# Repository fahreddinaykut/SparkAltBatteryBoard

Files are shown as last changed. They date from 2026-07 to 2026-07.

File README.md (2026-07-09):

# SparkAltBatteryBoard

A custom research-oriented battery interface and telemetry board for the DJI Spark platform, built around a standard 3S LiPo battery pack instead of the discontinued, hard-to-find OEM Smart Battery.

This project documents a reverse-engineered I2C/SMBus smart-battery communication interface, originally developed to study how the DJI Spark flight controller communicates with its battery pack. The board sits between a standard 3S pack and the drone, reads the real cell voltages and current, and reproduces that communication interface.

<p align="center">
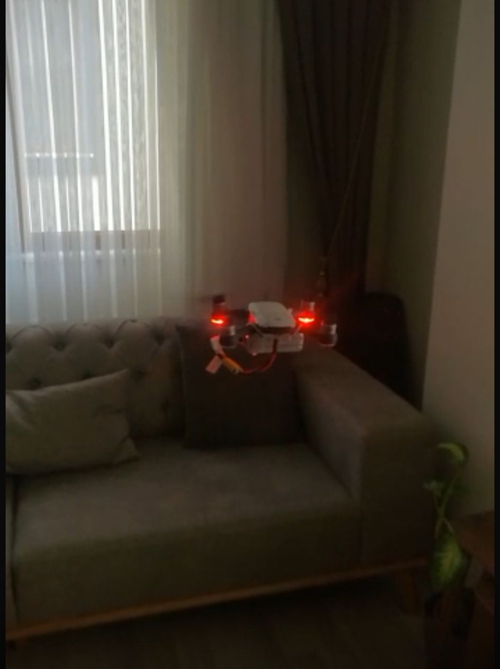
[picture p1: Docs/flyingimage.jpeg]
DJI Spark flying on SparkAltBatteryBoard
  
</p>

## How it works

1. The original DJI Spark Smart Battery was disassembled and its I2C/SMBus traffic with the flight controller was captured with a Saleae Logic Analyzer.
2. That traffic was decoded to recover the SBS + DJI-proprietary command set (auth handshake, cell voltages, PEC/CRC-8, etc.) — see [`Docs/I2C_BMS_PROTOCOL.md`](Docs/I2C_BMS_PROTOCOL.md).
3. A custom PCB replicates the OEM battery's form factor and connector, with resistor dividers for per-cell voltage sensing and an INA199 current shunt amplifier.
4. An ATmega328P on the board reproduces the Smart Battery communication interface over I2C in real time — computing PEC on the fly and clock-stretching where needed. See [`Firmware/README.md`](Firmware/README.md) for the full protocol implementation.

<p align="center">
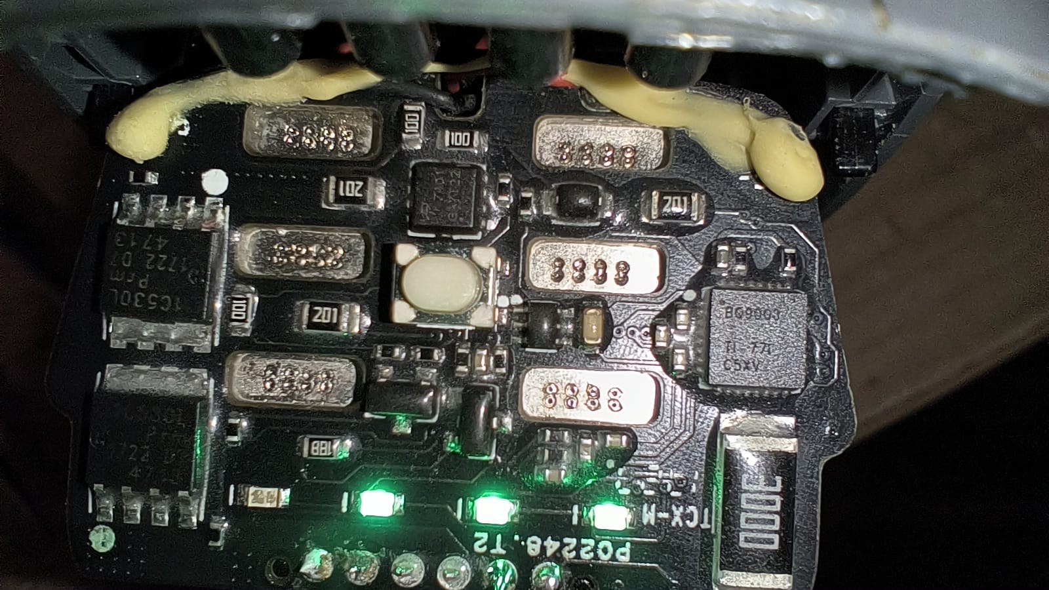
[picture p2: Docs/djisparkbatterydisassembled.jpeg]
Original DJI Spark battery, disassembled for reverse engineering
  
</p>

## Repository structure

| Folder | Contents |
|---|---|
| [`Hardware/`](Hardware) | KiCad project: schematics, PCB layout, 3D connector models, Gerbers, BOM |
| [`Firmware/`](Firmware) | PlatformIO project for the ATmega328P I2C/SMBus battery emulator |
| [`Mechanical/`](Mechanical) | Battery mount 3D model (STEP) |
| [`Docs/`](Docs) | Schematic PDF, protocol reverse-engineering notes, raw sniffed I2C sessions, reference photos/video |

## Hardware

| Top | Bottom | Layout |
|---|---|---|
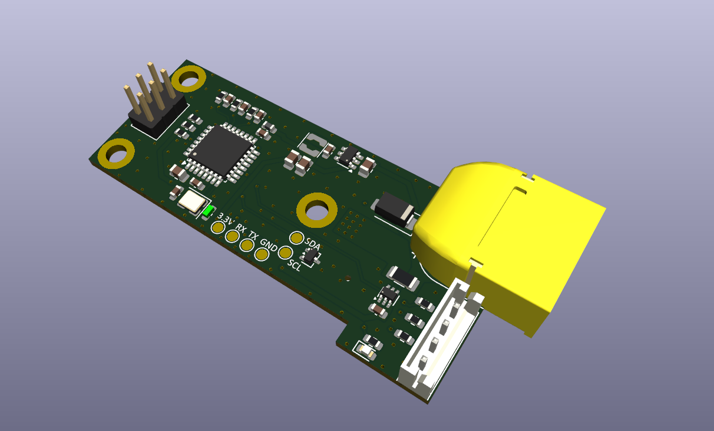
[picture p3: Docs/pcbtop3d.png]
PCB top 3D
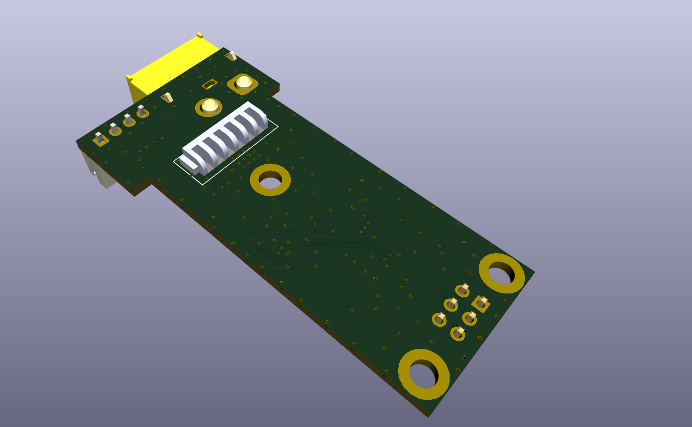
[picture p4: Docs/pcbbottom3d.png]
PCB bottom 3D
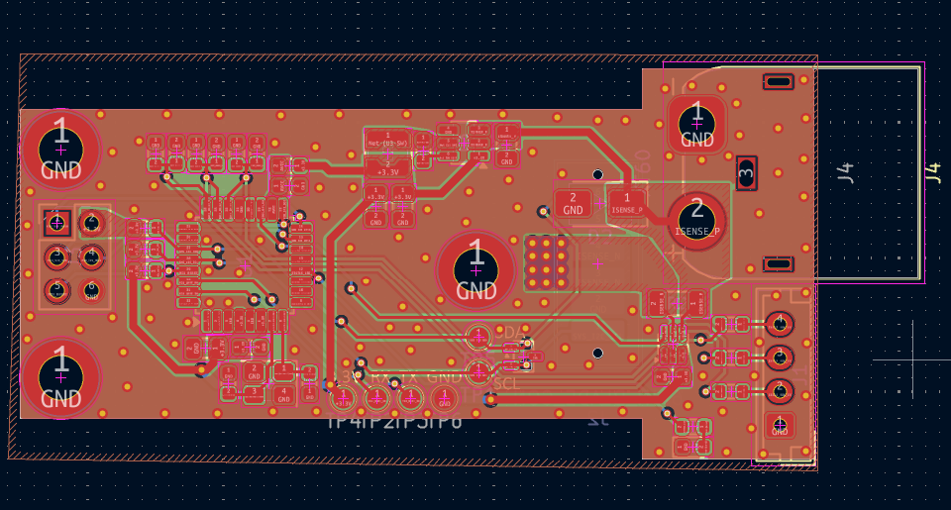
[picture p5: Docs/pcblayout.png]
PCB layout
|  |  |  |

- **MCU:** ATmega328P — chosen specifically because its hardware TWI peripheral supports I2C clock stretching reliably, which the DJI FC's polling requires (see [`Firmware/README.md`](Firmware/README.md#hardware) for why an ESP32 doesn't work here).
- **Sensing:** 3-way resistor divider network for per-cell voltage taps, INA199 shunt amplifier for pack current.
- **Full schematic:** [`Docs/SparkAltBatteryBoardV1.pdf`](Docs/SparkAltBatteryBoardV1.pdf)
- **Fabrication outputs:** [BOM](Hardware/Fabrication/SparkAltBatteryBoard_BOM.csv) · [Gerbers](Hardware/Fabrication/SparkAltBatteryBoard_Gerbers.zip)
- **Battery mount:** [`Mechanical/batterymount.stp`](Mechanical/batterymount.stp)

### PCB Design / Manufacturing Notes

The PCB revision was prepared as a manufacturing-oriented KiCad project, not only as a proof-of-concept schematic.

Design considerations include:

- Hierarchical schematic structure
- Separated MCU, power, sensing, and connector blocks
- 3.3 V I2C/SMBus logic interface
- ADC-scaled cell-voltage sensing inputs
- RC filtering on analog measurement lines
- INA199 high-side current-sense frontend
- Kelvin-style shunt measurement routing approach
- Buck-regulated 3.3 V system rail
- I2C pull-up resistors
- ESD/TVS protection on external communication lines
- AVR ICSP programming/debug header
- Wide copper routing/polygon strategy for battery current path
- Manufacturing outputs prepared: BOM and Gerber package

## Firmware

PlatformIO project targeting the ATmega328P (Arduino Uno/Nano pinout). Handles the I2C slave logic, ADC reads, CRC-8 PEC calculation, and all SBS/DJI command responses.

```
pio run -e uno
pio run -e uno -t upload
```

Full pin map, supported command table, and known limitations: [`Firmware/README.md`](Firmware/README.md).

## Protocol reverse engineering

The raw logic analyzer captures used to decode the protocol are included for reference:

- [`Docs/sniffedsession2.csv`](Docs/sniffedsession2.csv)
- [`Docs/sniffedsession3.csv`](Docs/sniffedsession3.csv)
- Full write-up: [`Docs/I2C_BMS_PROTOCOL.md`](Docs/I2C_BMS_PROTOCOL.md)

## Legacy Prototype Flight Test

The video below shows an earlier prototype tested around 4 years ago. It does not represent a flight test of the redesigned PCB revision in this repository.

<video src="Docs/flyingvideo.mp4" controls width="100%" poster="Docs/flyingimage.jpeg">
  Your browser can't play the embedded video — <a href="Docs/flyingvideo.mp4">watch/download it here</a>.
</video>

## Disclaimer

This is a hobbyist reverse-engineering project, shared for educational purposes. Flying with a modified battery/BMS is at your own risk — verify cell voltages, current limits, and wiring yourself before flight. Not affiliated with or endorsed by DJI.

The original prototype was flight-tested in the past. The redesigned PCB revision in this repository has not yet been flight-tested because the original test drone was later damaged in a crash.

## License

Source-available for personal, educational, and research use. Commercial use is not permitted without written permission. See [`LICENSE`](LICENSE) (MIT with Commons Clause).

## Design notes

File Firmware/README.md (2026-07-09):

# SparkAltBatteryBoard Firmware

Firmware that reproduces the I2C/SMBus communication interface of the DJI Spark's original Smart Battery. The goal is to respond correctly to the SBS + DJI proprietary commands expected by the flight controller (FC), so that a third-party/aftermarket 3S LiPo battery pack can be used without triggering an "Invalid Battery" error or an emergency landing.

## Hardware

- **Target MCU:** ATmega328P (`nanoatmega328` in PlatformIO, Arduino Uno/Nano pinout).
- **Why ATmega328P:** The DJI FC polls the battery at high speed, and the slave needs a few microseconds to compute the PEC (CRC-8) before responding. This requires hardware **clock stretching** on the I2C slave side (physically holding SCL low). Most modern 32-bit MCUs (e.g. ESP32) don't reliably support clock stretching in their I2C slave peripheral; the ATmega328P's native TWI module handles it correctly.
- **I2C slave address:** `0x0B` (standard SBS battery address).

### Pin map (`src/main.cpp`)

| Pin | Define | Purpose |
|---|---|---|
| A7 | `BATTERY_PIN_1` | BATCELL1 net — cell1 divider tap (4.7k/10k) |
| A0 (PC0) | `BATTERY_PIN_2` | BATCELL2 net — cell1+cell2 divider tap (20k/10k) |
| A1 (PC1) | `BATTERY_PIN_3` | BATCELL3 net — full pack divider tap (33k/10k) |
| A6 | `CURRENT_PIN` | INA199 shunt amplifier output (current sense) |
| A3 | `THERMISTOR_PIN` | NTC input — unused on the current hardware revision (see Known Limitations) |
| 8 | `LED_PIN` | I2C activity LED |
| A4 / A5 | SDA / SCL | I2C bus (Arduino `Wire` library defaults) |

Each divider tap shares a common 10kΩ bottom resistor against a different top resistor (4.7k / 20k / 33k), stepping down each cumulative cell voltage into the ADC's 0–3.3V range. `readVoltage()` takes the matching ratio (`CELL1_DIVIDER_RATIO`, `CELL2_DIVIDER_RATIO`, `PACK_DIVIDER_RATIO`) as a parameter for each pin.

## Protocol

- **Bus:** SMBus, little-endian byte order.
- **PEC (Packet Error Checking):** Every response ends with a CRC-8 byte (poly `0x07`, computed in `pec()`). If the FC can't validate this byte it rejects the data and can trigger an emergency landing, so every dynamic response function computes the PEC on the fly over `[address+W, command, address+R, data_lo, data_hi]`.
- Commands fall into two groups:
  - **Dynamic commands:** computed from live ADC measurements and sent.
  - **Static commands:** fixed bytes sniffed from the original DJI battery, sent back verbatim (auth/handshake, serial number, manufacturer name, etc.) — the FC only cares that these are always present and consistent, not that they're live.

### Supported commands

| Command | Meaning | Type |
|---|---|---|
| `0x08` | Temperature | Dynamic (currently fixed at 25°C — no NTC) |
| `0x09` | Pack Voltage | Dynamic |
| `0x0A` | Current | Dynamic (INA199) |
| `0x0D` | Relative State of Charge | Emulated / placeholder |
| `0x0F` | Remaining Capacity | Emulated / derived/static placeholder |
| `0x10` | Full Charge Capacity | Static |
| `0x17` | Cycle Count | Fixed (1) |
| `0x18` | Design Capacity | Static |
| `0x19` | Design Voltage | Static |
| `0x1B` | Manufacture Date | Static |
| `0x1C` | Serial Number | Static |
| `0x20` | Manufacturer Name | Static |
| `0x21` | Device Name | Static |
| `0x3D` / `0x3E` / `0x3F` | Cell3 / Cell2 / Cell1 Voltage | Dynamic |
| `0x00` | Manufacturer Data (mux, sub-page `0x51`/`0x53`/`0x54`/`0x55`) | Static |
| `0xD6` | Auth handshake (`55 AA 66`) | Static |
| `0xD8` | Barcode / serial | Static |
| `0xD9` | Encrypted firmware version | Static |
| `0xD2`, `0xD5`, `0xC2`, `0x23`, `0x66`, `0x2F` | Other DJI proprietary commands | Static |

Note: This firmware is not a calibrated fuel-gauge implementation. SOC and remaining-capacity related values are emulated for protocol compatibility and should not be used as accurate battery state estimation.

## Build & flash

With PlatformIO:

```
pio run -e uno
pio run -e uno -t upload
```

## File layout

- `src/main.cpp` — I2C slave logic, ADC reads, PEC calculation, all command responses.
- `platformio.ini` — build target: ATmega328P, 16MHz, Arduino framework.
- `DJISPoofer.xlsx` — raw I2C command/response data collected during reverse engineering (reference).

## Known limitations

- Temperature: the physical NTC was removed on the current hardware revision, so `getThermistorReading()` returns a fixed 25°C (`2982`, in 0.1K units).
- Values like Design Voltage, Design Capacity, and Cycle Count are static/fixed and independent of the actual hardware (should be set by hand to match the real battery spec).

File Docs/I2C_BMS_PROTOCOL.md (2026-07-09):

# DJI Spark BMS I2C/SMBus Protocol Reverse Engineering

This document outlines the decoded I2C/SMBus communication protocol between the DJI Spark Flight Controller (FC) and its proprietary Smart Battery. The data was sniffed and decoded using a Saleae Logic Analyzer.

By understanding this protocol, we can emulate the original DJI battery using a custom microcontroller, allowing the use of a standard 3S LiPo battery pack without triggering FC lockouts or emergency landings.

## 1. Physical Layer & Bus Fundamentals

DJI utilizes the industry-standard **Smart Battery Data Specification (SBS)** over SMBus, layered with their own proprietary authentication commands to lock down the ecosystem.

* **Bus Protocol:** SMBus @ 100kHz
* **Battery I2C Address:** `0x0B` (Standard SBS Address)
* **Logic Level:** 3.3V
* **Byte Order:** Little-Endian (Least Significant Byte first)
* **Integrity Check:** PEC (Packet Error Checking) using **CRC-8** (Polynomial `0x07`). 
  * *Critical:* Every read transaction must conclude with a valid PEC byte. If the PEC is missing or incorrectly calculated, the FC will immediately reject the data and trigger an emergency drop.

---

## 2. Standard SMBus Commands (Dynamic Telemetry)

The FC continuously polls the battery for real-time telemetry. The responses are typically 2 bytes of payload data followed by 1 byte of PEC.

* **`0x08` - Temperature:** * Example Payload: `0xB6 0x0B` -> `0x0BB6` = `2998`
  * Math: Value is in 0.1 Kelvin. (299.8 K = **26.65 °C**)
* **`0x09` - Pack Voltage:** * Example Payload: `0x8B 0x31` -> `0x318B` = `12683`
  * Math: Value is in mV. Result = **12.68 V**
* **`0x0A` - Current:** * Example Payload: `0xD3 0xFD` -> `0xFDD3` = `64979`
  * Math: Represented in Two's Complement for discharge. Result = **-557 mA**
* **`0x0D` - Relative State of Charge (SOC):** * Example Payload: `0x60 0x00` -> `0x0060` = `96`
  * Math: Result = **96%**
* **`0x0F` - Remaining Capacity:** * Example Payload: `0xA7 0x04` -> `0x04A7` = `1191`
  * Math: Value is in mAh. Result = **1191 mAh**
* **`0x17` - Cycle Count:** * Example Payload: `0x63 0x00` -> `0x0063` = `99`
  * Math: Result = **99 cycles**

---

## 3. DJI Proprietary Commands (The "Unknown" Hexes)

DJI extends the SBS standard to pull individual cell voltages and verify the hardware authenticity of the battery. If the custom board fails to provide the exact expected responses to these specific registers, the drone will display an "Invalid Battery" error and refuse to take off.

### A. Cell Voltages
* **`0x3F` - Cell 1 Voltage:** `0x81 0x10` -> `0x1081` = **4225 mV**
* **`0x3E` - Cell 2 Voltage:** `0x86 0x10` -> `0x1086` = **4230 mV**
* **`0x3D` - Cell 3 Voltage:** `0x84 0x10` -> `0x1084` = **4228 mV**

### B. Identification / Handshake Responses
* **`0xD6` - The Magic Handshake:** * Expected Response: `0x55 0xAA 0x66`
  * Note: `55 AA` is a well-known hardware boot signature. The FC uses this to confirm the BMS chip is running authorized firmware.
* **`0xD8` - Battery Serial / Barcode:** * Expected Response: `0x0E 0x30 0x43 0x30 0x41 0x45 0x39 0x56 0x42 0x33 0x33 0x30 0x31 0x53 0x51 0x60`
  * Decoded: The first byte (`0x0E`) is the length (14 characters). The rest is the ASCII representation of the physical barcode printed on the battery: **`0C0AE9VB3301SQ`**.
* **`0xD9` - Encrypted Firmware Version:** * Expected Response: `0x04 0xE2 0x17 0x83 0xD6 0xE3` (Static 4-byte versioning).
* **`0x20` - Manufacturer Name:** ASCII string returning `ATL NVT77777...`
* **`0x21` - Device Name:** ASCII string returning `DJI016ffff...`

---

## 4. The Multiplexer Mechanism (Command `0x00`)

The FC occasionally reads sub-pages of manufacturer data using `0x00` as a page selector/multiplexer.
1. **Write:** Master writes to `0x0B`: `0x00 0x51 0x00` (Instructs BMS to prep page `0x51`).
2. **Read:** Master reads from `0x0B` -> BMS returns block data: `0x04 0x00 0x00 0x00 0x00 0x54`.

The FC repeats this polling for sub-pages `0x51`, `0x53`, `0x54`, and `0x55`. The custom firmware must cache the last requested sub-page address and serve the corresponding static byte array upon the subsequent read request.

---

## 5. Emulation Strategy

To reproduce the expected smart-battery communication behavior:
1. **Dynamic Data:** Read physical analog values via ADC (Overall Voltage, Current via INA199) and map them dynamically to commands `0x09`, `0x0A`, `0x0D`, `0x0F`, `0x3D`, `0x3E`, `0x3F`.
2. **Static Spoofing:** Return hardcoded byte arrays for the authentication commands (`0xD6`, `0xD8`, `0xD9`, `0x20`, `0x21`). The FC does not care if the serial number is always the same, as long as it exists and is formatted correctly.
3. **Flawless CRC:** Pass the `[Address + Read/Write Bit]`, `[Command]`, and `[Payload]` through the CRC-8 algorithm. Append the resulting PEC byte to the end of every transmission. 

---

## 6. Hardware Constraints: The Clock Stretching Trap

When selecting a microcontroller to emulate the DJI Smart Battery, processing speed is less important than low-level hardware protocol compliance. 

The DJI Flight Controller interrogates the battery at high speeds. When the FC requests dynamic data (like cell voltages) or requires a PEC (CRC-8) calculation on the fly, the emulation MCU needs a few microseconds to compute the response before transmitting. 

To prevent the FC from reading incomplete data during this computation window, the emulation MCU **must** physically pull the SCL (Clock) line LOW. This forces the Master (FC) to pause. This mechanism is known as **I2C Clock Stretching**.

**Why AVR / ATmega328P?**
Many modern, high-clock-speed, 32-bit microcontrollers (like the ESP32) have notoriously flawed or strictly software-emulated I2C Slave hardware that fails to execute Clock Stretching reliably. If the clock is not stretched properly, the FC reads garbage data, assumes a catastrophic battery failure, and initiates an immediate drop/shutdown.

The ATmega328P was explicitly chosen for this architecture because its native hardware TWI (Two-Wire Interface) module handles I2C Slave operations and Clock Stretching flawlessly at the silicon level, ensuring the drone's FC never experiences a bus timeout or corrupted packet.

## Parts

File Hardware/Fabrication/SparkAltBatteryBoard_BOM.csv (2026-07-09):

Reference | Qty | Value | DNP | Footprint | LCSC Part
C2,C6,C10,C11,C12,C13,C14 | 7 | 100nF |  | Capacitor_SMD:C_0603_1608Metric | C235731
C3,C7,C8,C9 | 4 | 22uF |  | Capacitor_SMD:C_0805_2012Metric | C33546009
C4,C5 | 2 | 18pF |  | Capacitor_SMD:C_0603_1608Metric | C5137620
D2 | 1 | SMAJ15A |  | Diode_SMD:D_SMA | C19077535
D3 | 1 | LED_Small |  | LED_SMD:LED_0603_1608Metric | C2682775
J1 | 1 | JST-XH-4P |  | Connector_JST:JST_EH_B4B-EH-A_1x04_P2.50mm_Vertical | C144395
J2 | 1 | 6PIN_BLADE_CON | DNP | KardLab:Female_Blade_Socket_2mm_6P | DNP
J3 | 1 | AVR ICSP |  | Connector_PinHeader_2.54mm:PinHeader_2x03_P2.54mm_Vertical | C42431837
J4 | 1 | XT60 |  | Connector_AMASS:AMASS_XT60IPW-M_1x03_P7.20mm_Horizontal | C98732
L1 | 1 | MGFL1608F100MT-LF |  | Inductor_SMD:L_0603_1608Metric | C281107
L2 | 1 | SFE3015A-4R7M-F-HF |  | Inductor_SMD:L_Coilcraft_LPS3010 | C5159666
R2 | 1 | 2mR |  | Resistor_SMD:R_1206_3216Metric | C49164932
R3,R8,R10,R12 | 4 | 10K |  | Resistor_SMD:R_0603_1608Metric | C2930027
R4 | 1 | 1K |  | Resistor_SMD:R_0603_1608Metric | C2907002
R5,R6 | 2 | 5.1K |  | Resistor_SMD:R_0603_1608Metric | C2907044
R7 | 1 | 4.7K |  | Resistor_SMD:R_0603_1608Metric | C163914
R9 | 1 | 20K |  | Resistor_SMD:R_0603_1608Metric | C2907124
R11 | 1 | 33K |  | Resistor_SMD:R_0603_1608Metric | C880143
TP1,TP2,TP3,TP4,TP5,TP6 | 6 | DNP | DNP | TestPoint:TestPoint_Pad_D1.5mm | DNP
U1 | 1 | ATmega328P-A |  | Package_QFP:TQFP-32_7x7mm_P0.8mm | C14877
U2 | 1 | INA199xxDCK |  | Package_TO_SOT_SMD:SOT-363_SC-70-6 | C59135
U3 | 1 | AP63203WU |  | Package_TO_SOT_SMD:TSOT-23-6 | C780769
U4 | 1 | TPD2E2U06DCK |  | Package_TO_SOT_SMD:SOT-323_SC-70 | C5350871
Y1 | 1 | X32258MOB4SI |  | Crystal:Crystal_SMD_3225-4Pin_3.2x2.5mm | C2682775

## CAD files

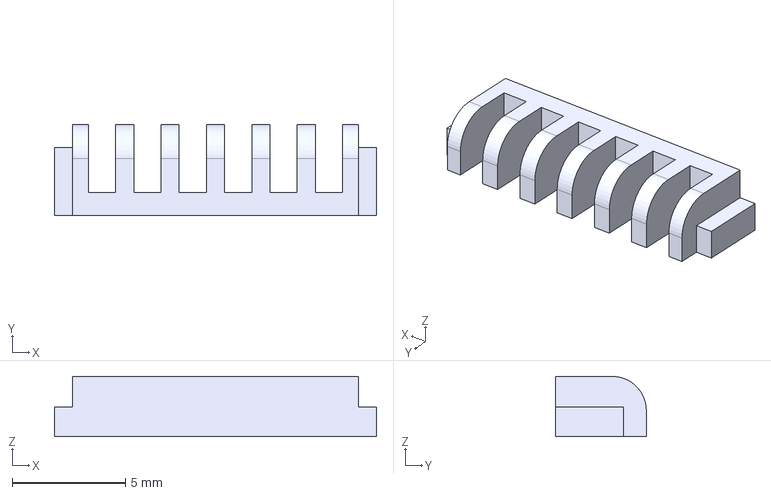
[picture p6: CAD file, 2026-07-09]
Hardware/3dmodels/femaleconnector.stp
14.2 x 4.00 x 2.65 mm

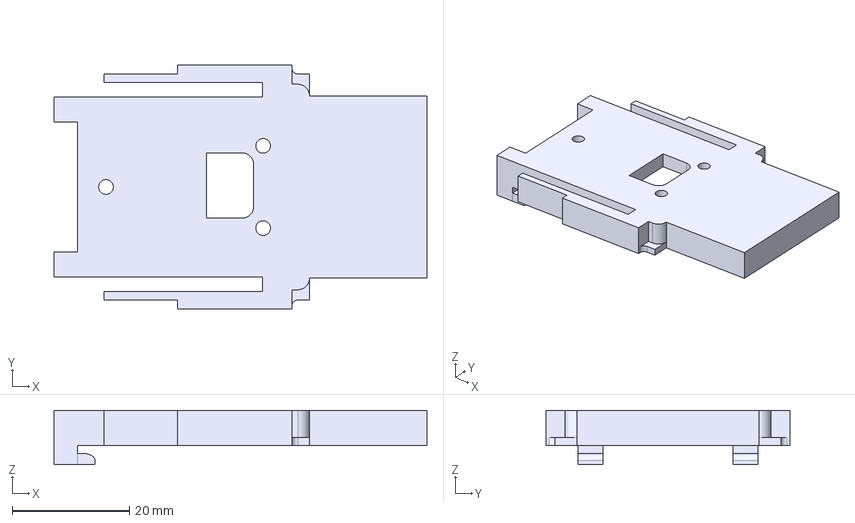
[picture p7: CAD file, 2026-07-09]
Mechanical/batterymount.stp
63.5 x 41.5 x 9.25 mm

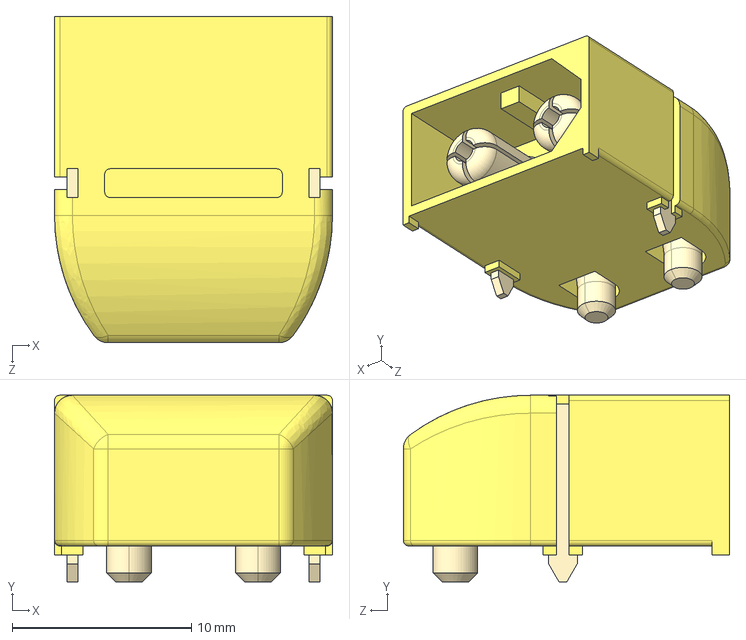
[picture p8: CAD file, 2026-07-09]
Hardware/3dmodels/XT60PW MALE.STEP
15.5 x 10.4 x 18.2 mm

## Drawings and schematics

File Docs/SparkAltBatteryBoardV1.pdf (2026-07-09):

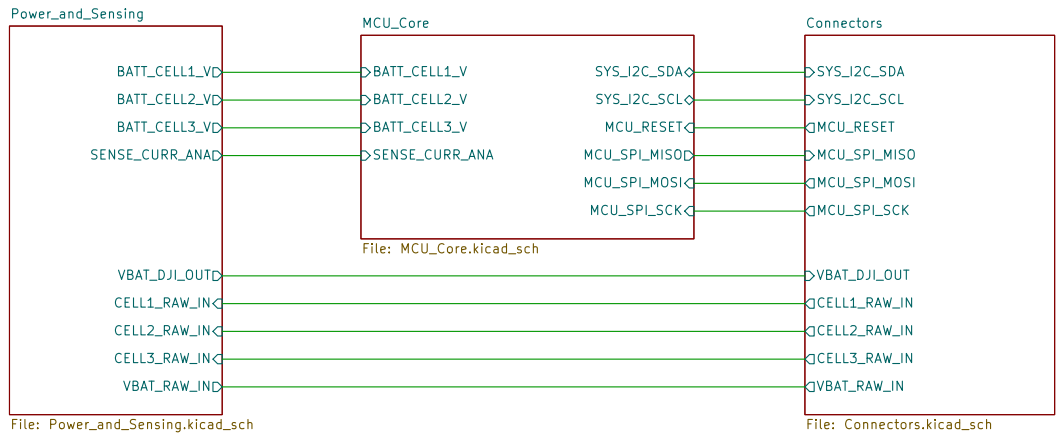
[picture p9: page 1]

Integrated Telemetry & I2C BMS Handshake via ATmega328P
Target Payload: 3S LiHV / 15A Cont. (30A Peak) Load
Fahreddin Esad Aykut
Sheet: /
File: SparkAltBatteryBoardV1.kicad_sch
Title: SparkAltBatteryBoard - Main System Architecture

Size: A4 | Rev: v1.0
KiCad E.D.A. 10.0.1 | Id: 1/4

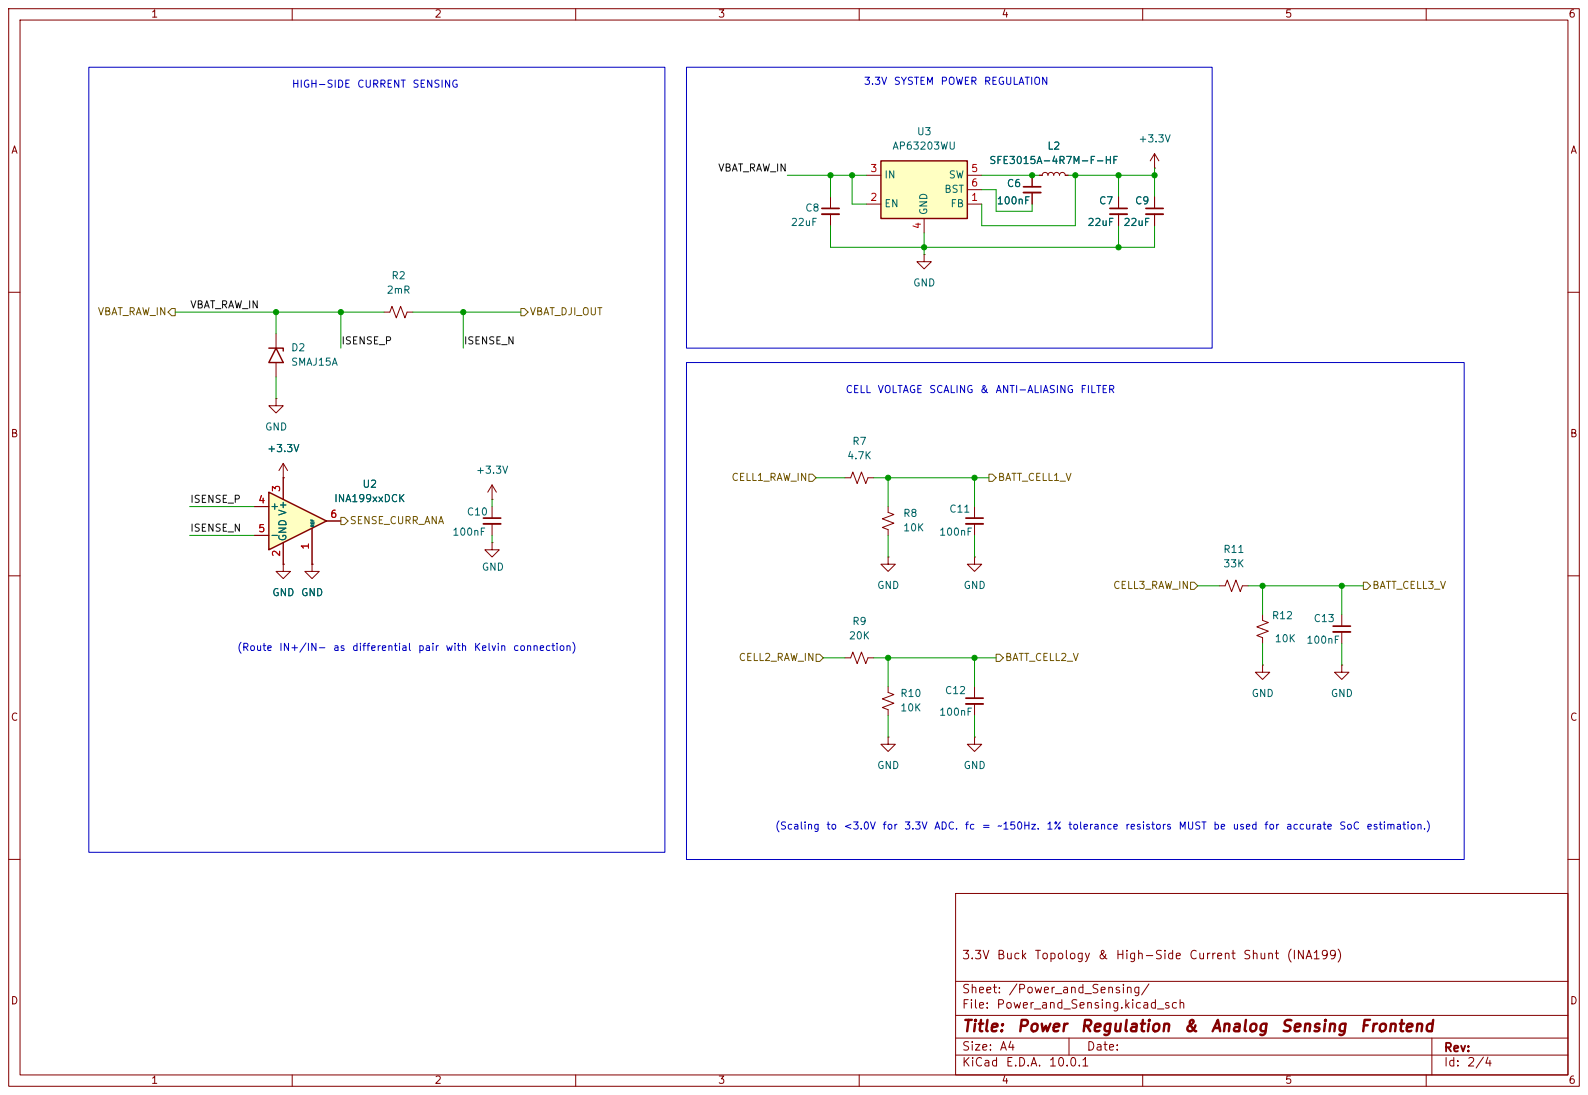
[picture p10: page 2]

CELL VOLTAGE SCALING & ANTI-ALIASING FILTER HIGH-SIDE CURRENT SENSING

3.3V Buck Topology & High-Side Current Shunt (INA199) C11

(Route IN+/IN- as differential pair with Kelvin connection)

(Scaling to <3.0V for 3.3V ADC. fc = ~150Hz. 1% tolerance resistors MUST be used for accurate SoC estimation.)

Sheet: /Power_and_Sensing/
File: Power_and_Sensing.kicad_sch
Title: Power Regulation & Analog Sensing Frontend

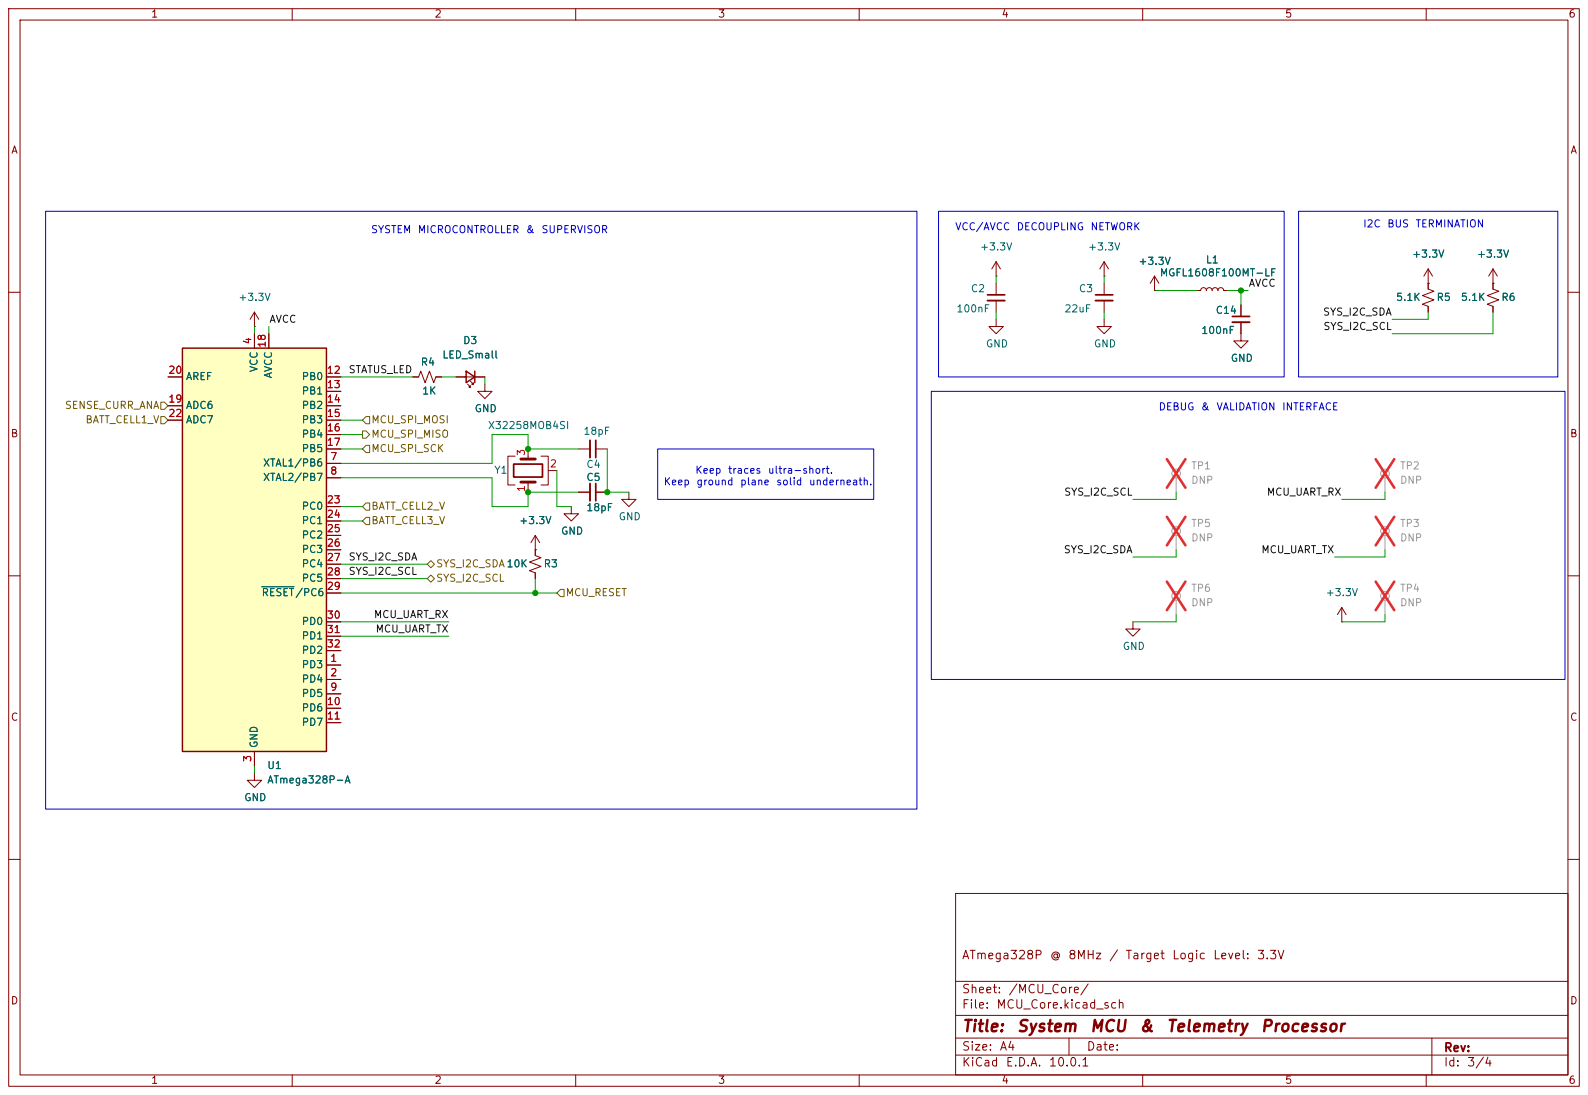
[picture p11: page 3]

Sheet: /MCU_Core/
File: MCU_Core.kicad_sch
Title: System MCU & Telemetry Processor

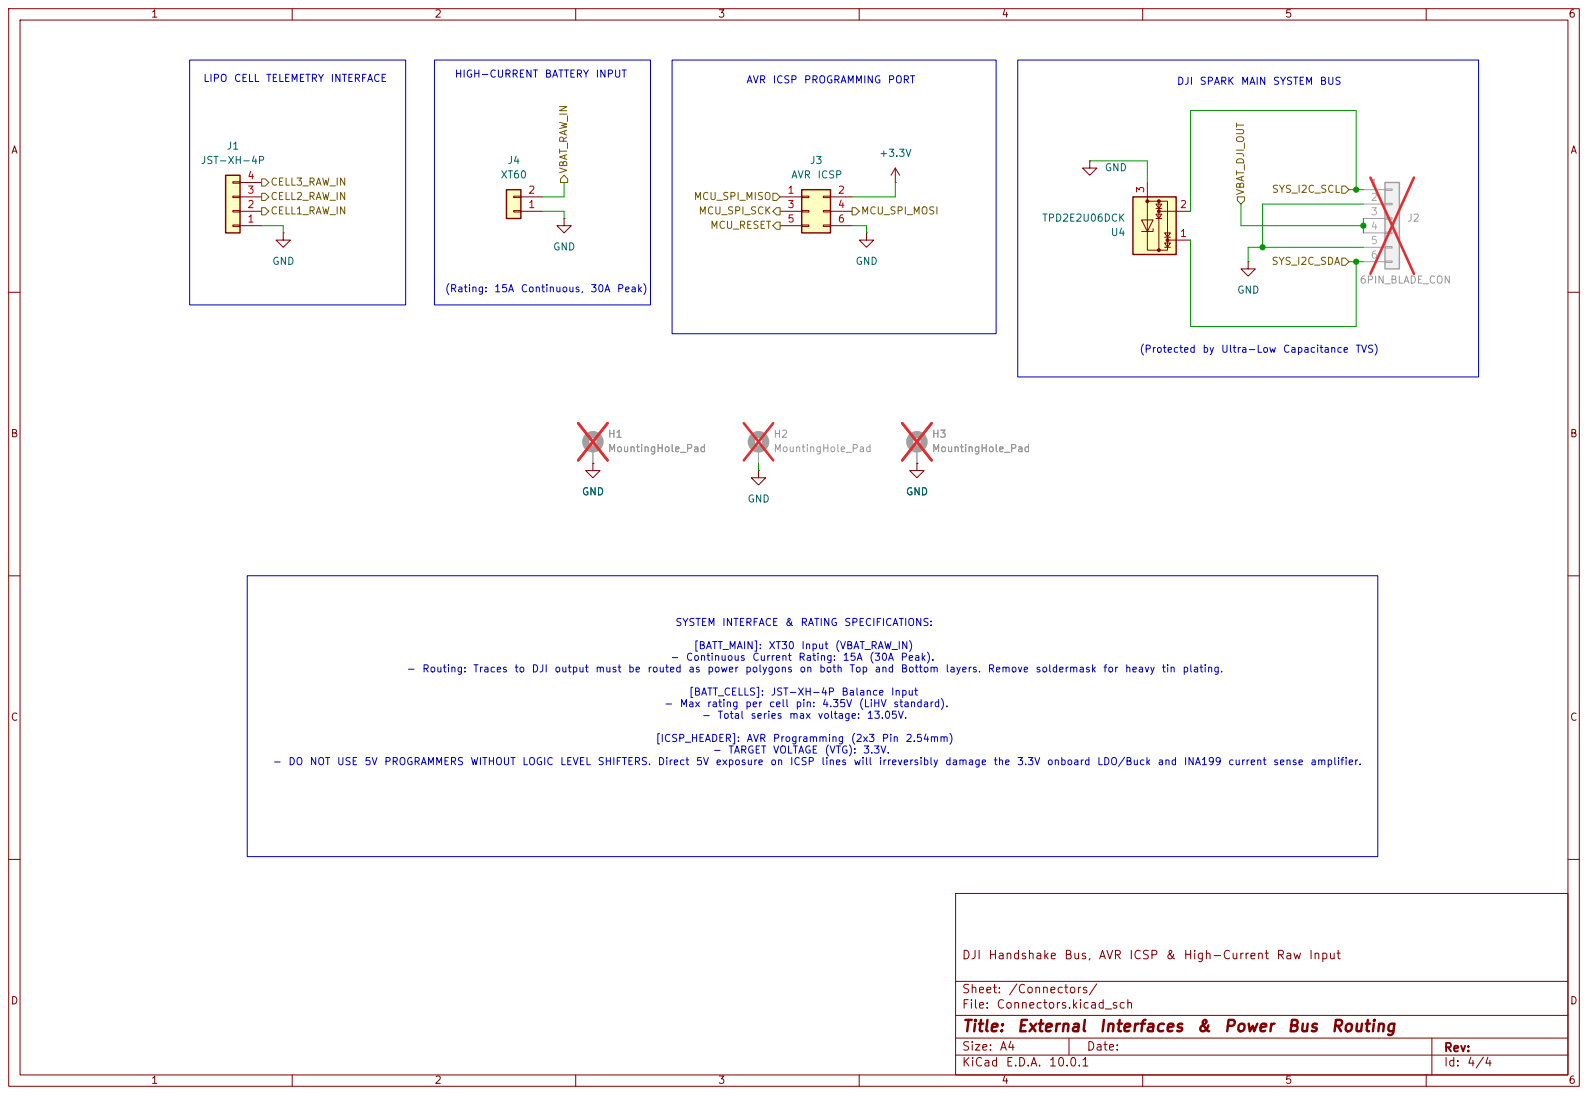
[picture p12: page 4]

DJI SPARK MAIN SYSTEM BUS

(Protected by Ultra-Low Capacitance TVS)

DJI Handshake Bus, AVR ICSP & High-Current Raw Input GND

SYSTEM INTERFACE & RATING SPECIFICATIONS: [BATT_MAIN]: XT30 Input (VBAT_RAW_IN) - Continuous Current Rating: 15A (30A Peak). - Routing: Traces to DJI output must be routed as power polygons on both Top and Bottom layers. Remove soldermask for heavy tin plating.

[BATT_CELLS]: JST-XH-4P Balance Input - Max rating per cell pin: 4.35V (LiHV standard). - Total series max voltage: 13.05V. [ICSP_HEADER]: AVR Programming (2x3 Pin 2.54mm) - TARGET VOLTAGE (VTG): 3.3V. - DO NOT USE 5V PROGRAMMERS WITHOUT LOGIC LEVEL SHIFTERS. Direct 5V exposure on ICSP lines will irreversibly damage the 3.3V onboard LDO/Buck and INA199 current sense amplifier.

Sheet: /Connectors/
File: Connectors.kicad_sch
Title: External Interfaces & Power Bus Routing

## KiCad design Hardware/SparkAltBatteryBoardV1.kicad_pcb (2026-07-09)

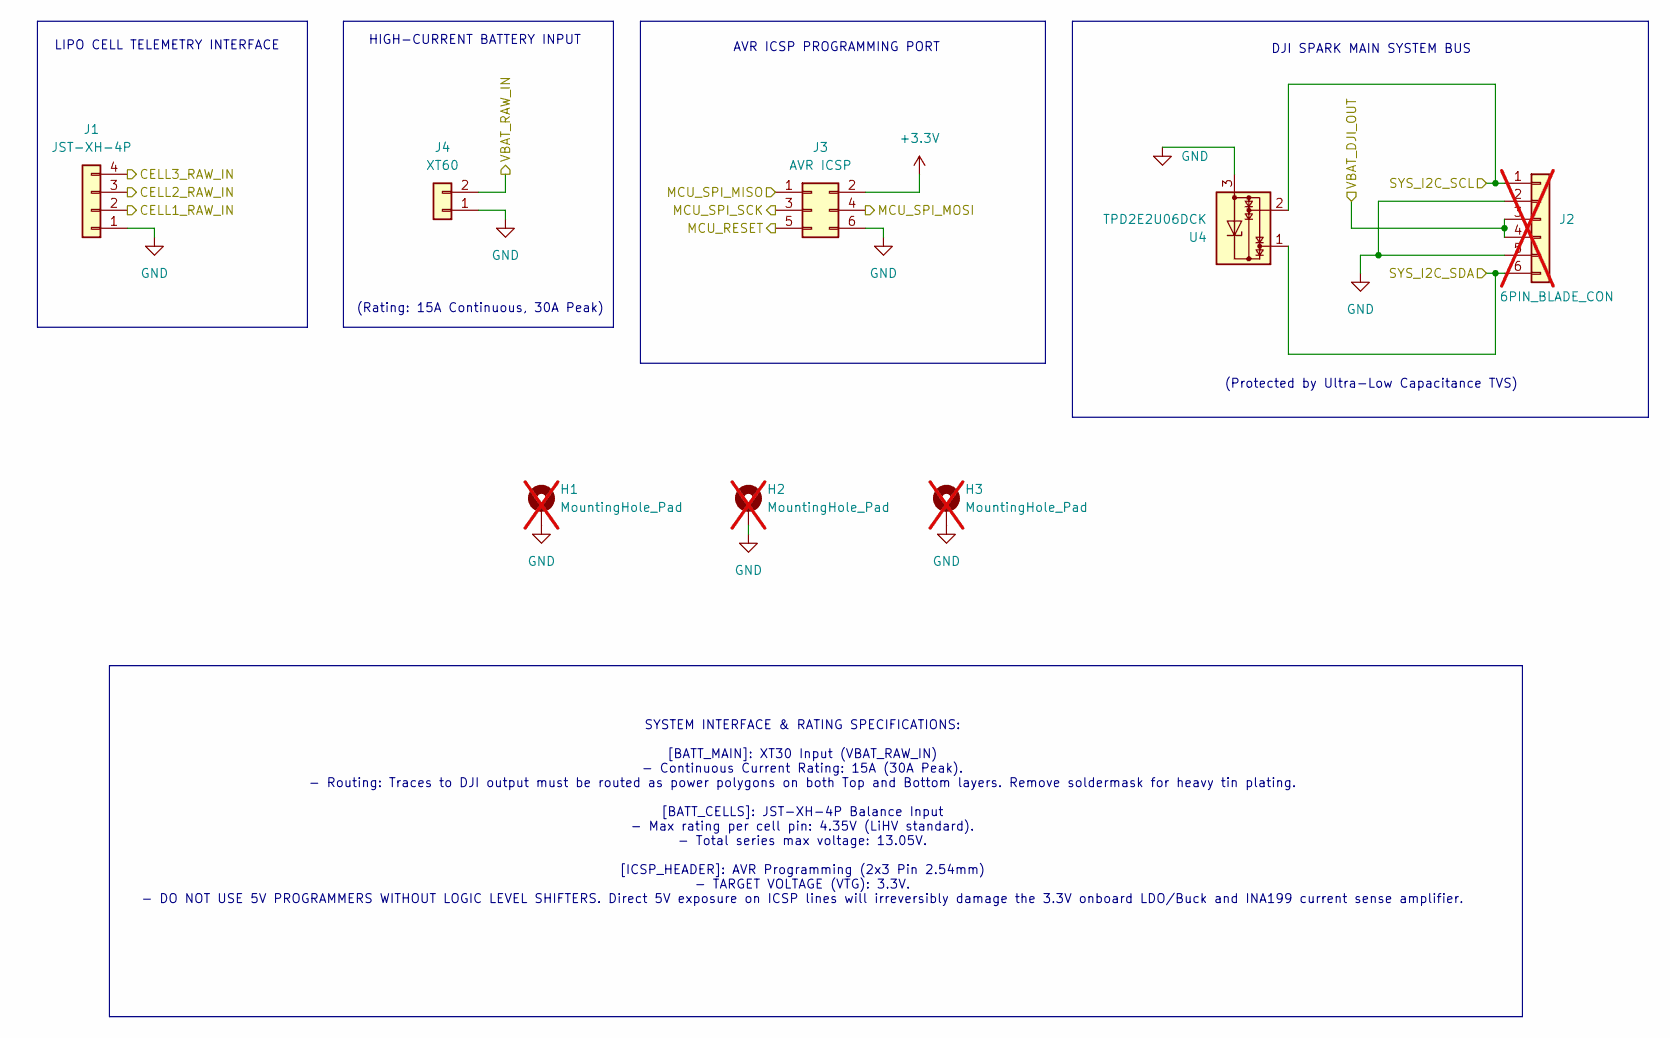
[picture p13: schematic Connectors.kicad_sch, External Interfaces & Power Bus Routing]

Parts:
H1, H2, H3: MountingHole_Pad; MountingHole_3.2mm_M3_DIN965_Pad; LCSC Part DNP; not fitted
J1: JST-XH-4P; JST_EH_B4B-EH-A_1x04_P2.50mm_Vertical; LCSC Part C144395
J2: 6PIN_BLADE_CON; Female_Blade_Socket_2mm_6P; LCSC Part DNP; not fitted
J3: AVR ICSP; PinHeader_2x03_P2.54mm_Vertical; LCSC Part C42431837
J4: XT60; AMASS_XT60IPW-M_1x03_P7.20mm_Horizontal; LCSC Part C98732
U4: TPD2E2U06DCK; SOT-323_SC-70; LCSC Part C5350871

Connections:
+3.3V: J3.2; also elsewhere on the board
/Connectors/CELL1_RAW_IN: J1.2; also elsewhere on the board
/Connectors/CELL2_RAW_IN: J1.3; also elsewhere on the board
/Connectors/CELL3_RAW_IN: J1.4; also elsewhere on the board
/Connectors/MCU_RESET: J3.5; also elsewhere on the board
/Connectors/MCU_SPI_MISO: J3.1; also elsewhere on the board
/Connectors/MCU_SPI_MOSI: J3.4; also elsewhere on the board
/Connectors/MCU_SPI_SCK: J3.3; also elsewhere on the board
/MCU_Core/SYS_I2C_SCL: J2.1, U4.2; also elsewhere on the board
/MCU_Core/SYS_I2C_SDA: J2.6, U4.1; also elsewhere on the board
/Power_and_Sensing/ISENSE_N: J2.3, J2.4; also elsewhere on the board
/Power_and_Sensing/ISENSE_P: J4.2; also elsewhere on the board
GND: H1.1 (1_1), H2.1 (1_1), H3.1 (1_1), J1.1, J2.2, J2.5, J3.6, J4.1, U4.3; also elsewhere on the board

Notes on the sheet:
(Rating: 15A Continuous, 30A Peak)
AVR ICSP PROGRAMMING PORT
DJI SPARK MAIN SYSTEM BUS
(Protected by Ultra-Low Capacitance TVS)
LIPO CELL TELEMETRY INTERFACE
SYSTEM INTERFACE & RATING SPECIFICATIONS: [BATT_MAIN]: XT30 Input (VBAT_RAW_IN) - Continuous Current Rating: 15A (30A Peak). - Routing: Traces to DJI output must be routed as power polygons on both Top and Bottom layers. Remove soldermask for heavy tin plating. [BATT_CELLS]: JST-XH-4P Balance Input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
HIGH-CURRENT BATTERY INPUT

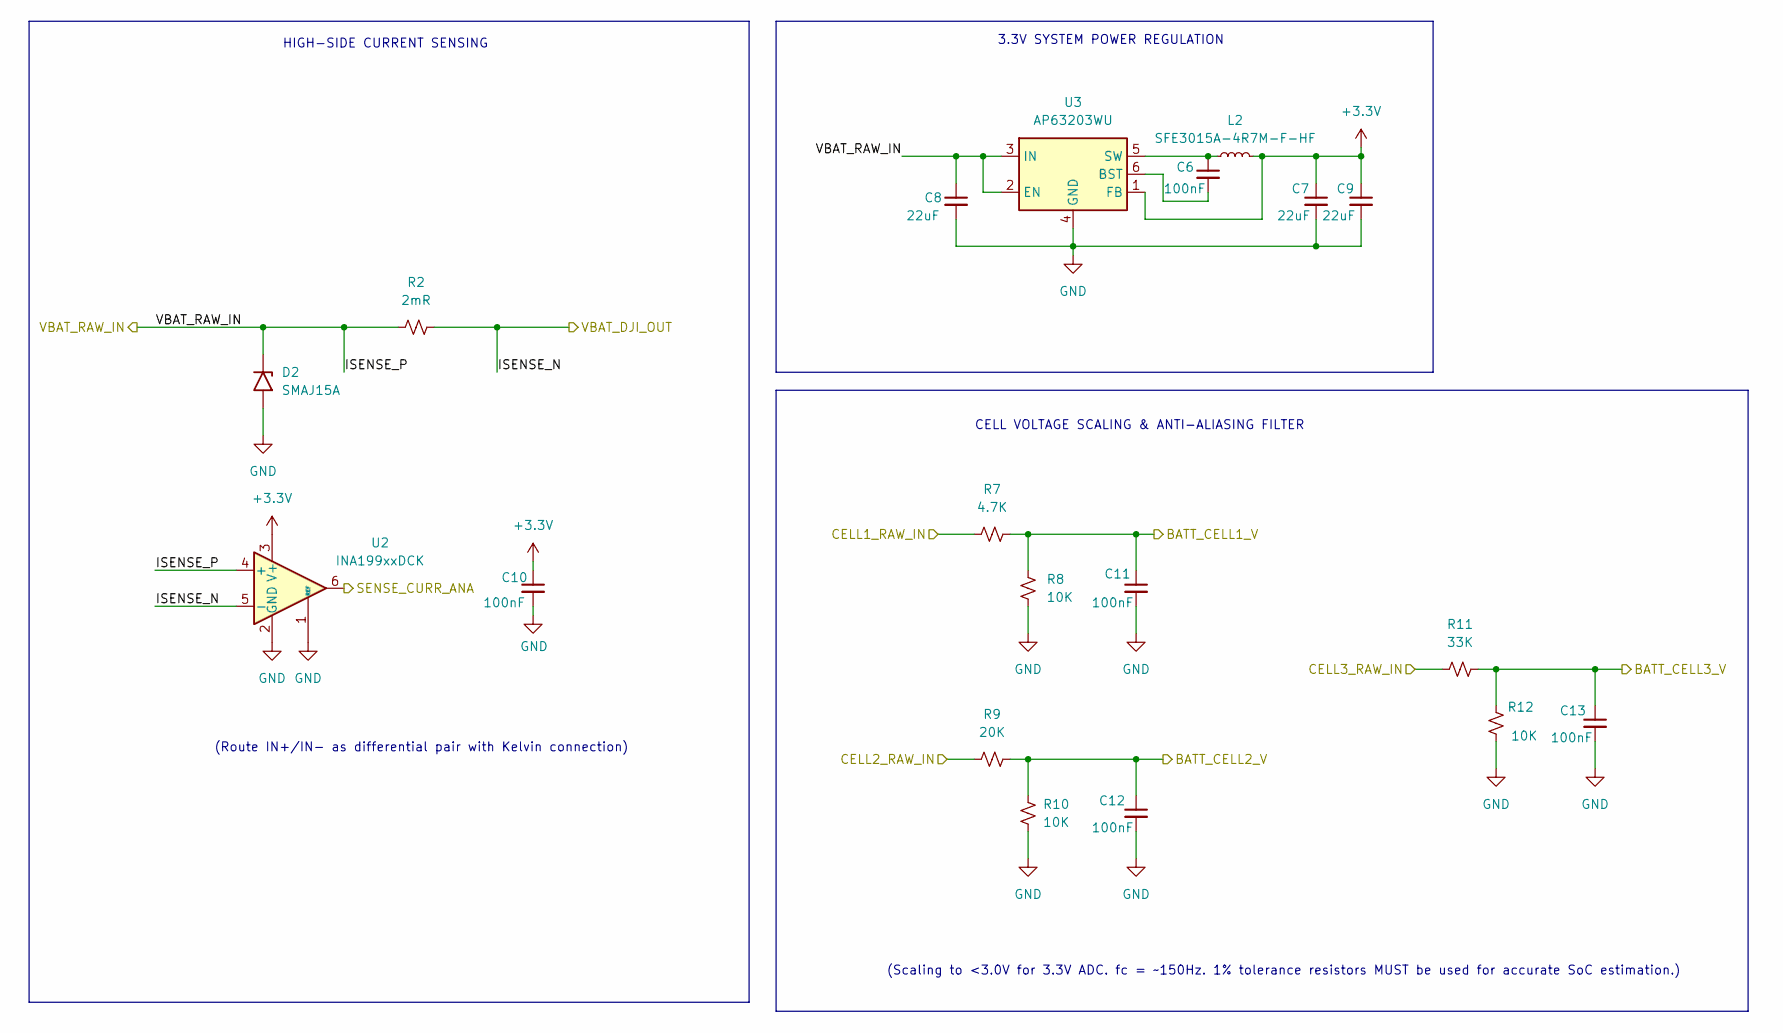
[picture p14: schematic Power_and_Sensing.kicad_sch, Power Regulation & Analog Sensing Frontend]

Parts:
C6, C10, C11, C12, C13: 100nF; C_0603_1608Metric; LCSC Part C235731
C7, C8, C9: 22uF; C_0805_2012Metric; LCSC Part C33546009
D2: SMAJ15A; D_SMA; LCSC Part C19077535
L2: SFE3015A-4R7M-F-HF; L_Coilcraft_LPS3010; LCSC Part C5159666
R2: 2mR; R_1206_3216Metric; LCSC Part C49164932
R7: 4.7K; R_0603_1608Metric; LCSC Part C163914
R8, R10, R12: 10K; R_0603_1608Metric; LCSC Part C2930027
R9: 20K; R_0603_1608Metric; LCSC Part C2907124
R11: 33K; R_0603_1608Metric; LCSC Part C880143
U2: INA199xxDCK; SOT-363_SC-70-6; LCSC Part C59135
U3: AP63203WU; TSOT-23-6; LCSC Part C780769

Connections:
+3.3V: C7.1, C9.1, C10.1, L2.2, U2.3 (V+), U3.1 (FB); also elsewhere on the board
/Connectors/CELL1_RAW_IN: R7.1; also elsewhere on the board
/Connectors/CELL2_RAW_IN: R9.1; also elsewhere on the board
/Connectors/CELL3_RAW_IN: R11.1; also elsewhere on the board
/MCU_Core/BATT_CELL1_V: C11.1, R7.2, R8.2; also elsewhere on the board
/MCU_Core/BATT_CELL2_V: C12.1, R9.2, R10.2; also elsewhere on the board
/MCU_Core/BATT_CELL3_V: C13.1, R11.2, R12.2; also elsewhere on the board
/MCU_Core/SENSE_CURR_ANA: U2.6; also elsewhere on the board
/Power_and_Sensing/ISENSE_N: R2.2, U2.5 (-); also elsewhere on the board
/Power_and_Sensing/ISENSE_P: C8.1, D2.1 (A1), R2.1, U2.4 (+), U3.2 (EN), U3.3 (IN); also elsewhere on the board
GND: C7.2, C8.2, C9.2, C10.2, C11.2, C12.2, C13.2, D2.2 (A2), R8.1, R10.1, R12.1, U2.1 (REF), U2.2 (GND), U3.4 (GND); also elsewhere on the board
unnamed: C6.2, U3.6 (BST)
unnamed: C6.1, L2.1, U3.5 (SW)

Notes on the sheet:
3.3V SYSTEM POWER REGULATION
(Route IN+/IN- as differential pair with Kelvin connection)
HIGH-SIDE CURRENT SENSING
(Scaling to <3.0V for 3.3V ADC. fc = ~150Hz. 1% tolerance resistors MUST be used for accurate SoC estimation.)
CELL VOLTAGE SCALING & ANTI-ALIASING FILTER

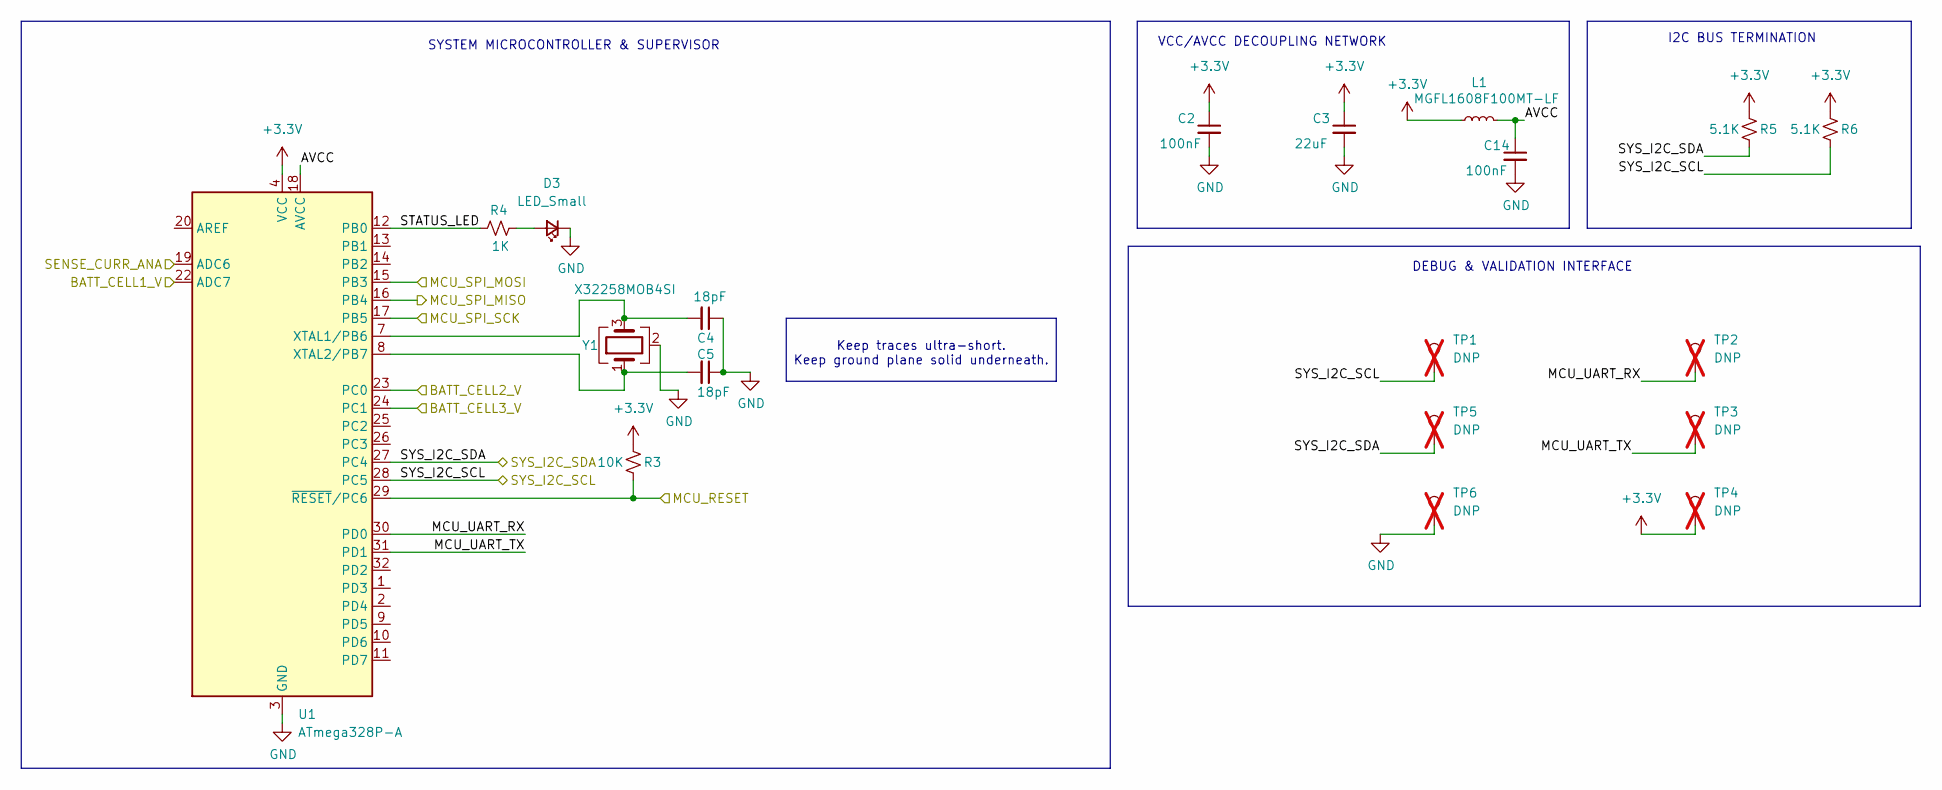
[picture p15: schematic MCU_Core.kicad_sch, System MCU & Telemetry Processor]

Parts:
C2, C14: 100nF; C_0603_1608Metric; LCSC Part C235731
C3: 22uF; C_0805_2012Metric; LCSC Part C33546009
C4, C5: 18pF; C_0603_1608Metric; LCSC Part C5137620
D3: LED_Small; LED_0603_1608Metric; LCSC Part C965808
L1: MGFL1608F100MT-LF; L_0603_1608Metric; LCSC Part C281107
R3: 10K; R_0603_1608Metric; LCSC Part C2930027
R4: 1K; R_0603_1608Metric; LCSC Part C2907002
R5, R6: 5.1K; R_0603_1608Metric; LCSC Part C2907044
TP1, TP2, TP3, TP4, TP5, TP6: DNP; TestPoint_Pad_D1.5mm; LCSC Part DNP; not fitted
U1: ATmega328P-A; TQFP-32_7x7mm_P0.8mm; LCSC Part C14877
Y1: X32258MOB4SI; Crystal_SMD_3225-4Pin_3.2x2.5mm; LCSC Part C2682775

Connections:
+3.3V: C2.1, C3.1, L1.1, R3.2, R5.2, R6.2, TP4.1 (1_1), U1.4 (VCC), U1.6 (VCC); also elsewhere on the board
/Connectors/MCU_RESET: R3.1, U1.29 (~RESET/PC6); also elsewhere on the board
/Connectors/MCU_SPI_MISO: U1.16 (PB4); also elsewhere on the board
/Connectors/MCU_SPI_MOSI: U1.15 (PB3); also elsewhere on the board
/Connectors/MCU_SPI_SCK: U1.17 (PB5); also elsewhere on the board
/MCU_Core/AVCC: C14.1, L1.2, U1.18 (AVCC)
/MCU_Core/BATT_CELL1_V: U1.22 (ADC7); also elsewhere on the board
/MCU_Core/BATT_CELL2_V: U1.23 (PC0); also elsewhere on the board
/MCU_Core/BATT_CELL3_V: U1.24 (PC1); also elsewhere on the board
/MCU_Core/MCU_UART_RX: TP2.1 (1_1), U1.30 (PD0)
/MCU_Core/MCU_UART_TX: TP3.1 (1_1), U1.31 (PD1)
/MCU_Core/SENSE_CURR_ANA: U1.19 (ADC6); also elsewhere on the board
/MCU_Core/STATUS_LED: R4.2, U1.12 (PB0)
/MCU_Core/SYS_I2C_SCL: R6.1, TP1.1 (1_1), U1.28 (PC5); also elsewhere on the board
/MCU_Core/SYS_I2C_SDA: R5.1, TP5.1 (1_1), U1.27 (PC4); also elsewhere on the board
GND: C2.2, C3.2, C4.1, C5.1, C14.2, D3.1 (K), TP6.1 (1_1), U1.3 (GND), U1.5 (GND), U1.21 (GND), Y1.2 (G), Y1.4 (G); also elsewhere on the board
unnamed: D3.2 (A), R4.1
unnamed: C4.2, U1.7 (XTAL1/PB6), Y1.3
unnamed: C5.2, U1.8 (XTAL2/PB7), Y1.1

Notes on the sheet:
SYSTEM MICROCONTROLLER & SUPERVISOR
Keep traces ultra-short. Keep ground plane solid underneath.
I2C BUS TERMINATION
VCC/AVCC DECOUPLING NETWORK
DEBUG & VALIDATION INTERFACE

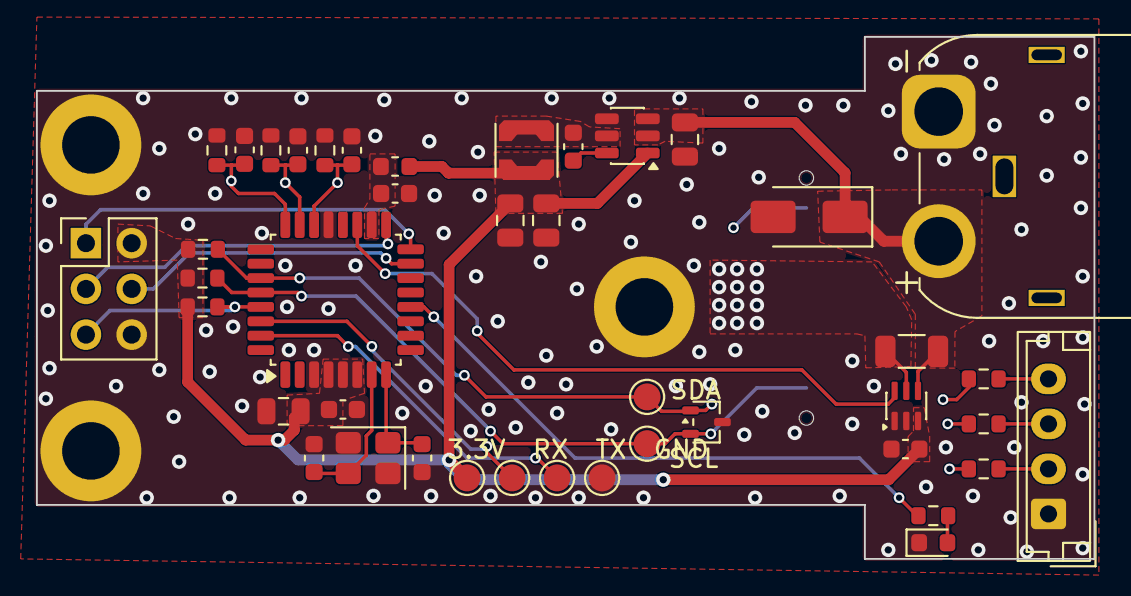
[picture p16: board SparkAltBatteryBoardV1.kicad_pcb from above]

Board: 4 copper layers, 58.8 x 29.0 mm, 46 parts (1 on the bottom side), 26 nets.

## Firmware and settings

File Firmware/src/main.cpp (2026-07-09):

#include <Arduino.h>
#include <Wire.h>

#define Unknown0xD5Request 0xD5
#define DesignCapacityRequest 0x18
#define CycleCountRequest 0x17
#define DesignVoltageRequest 0x19
#define ManufactureDateRequest 0x1B
#define SerialNumberRequest 0x1C
#define ManufacturerNameRequest 0x20
#define DeviceNameRequest 0x21
#define ManufacturerDataRequest 0x00

#define PackVoltageRequest 0x09
#define CurrentRequest 0x0A
#define FullChargeCapacityRequest 0x10
#define RemainingCapacityRequest 0x0F
#define TemperatureRequest 0x08
#define RelativeStateOfChargeRequest 0x0D
#define Unknown0x51Request 0x51
#define Unknown0xD2Request 0xD2
#define CellVoltage1Request 0x3F
#define CellVoltage2Request 0x3E
#define CellVoltage3Request 0x3D
#define Unknown0xD6Request 0xD6
#define Unknown0xD9Request 0xD9
#define Unknown0xD8Request 0xD8
#define Unknown0xC2Request 0xC2

#define ManufacturerReadRequest 0x23
#define Unkown0x66Request 0x66
#define Unknown0x2FRequest 0x2F

#define BATTERY_PIN_1 A7 // BATCELL1 net: cell1 tap
#define BATTERY_PIN_2 A0 // BATCELL2 net: cell1+cell2 tap (PC0)
#define BATTERY_PIN_3 A1 // BATCELL3 net: full pack tap (PC1)
#define THERMISTOR_PIN A3
#define CURRENT_PIN A6 // INA199 shunt amplifier output
#define LED_PIN 8
#define ADCReferanceVoltage 3.3f
// Each ADC tap has its own top resistor (Rtop) against a shared 10k bottom resistor (Rbottom),
// ratio = Rbottom / (Rtop + Rbottom). Bigger tap voltage needs a bigger Rtop to stay in ADC range.
constexpr float CELL1_DIVIDER_RATIO = 10.0f / (4.7f + 10.0f); // BATTERY_PIN_1 (BATCELL1): cell1 tap, 4.7k/10k
constexpr float CELL2_DIVIDER_RATIO = 10.0f / (20.0f + 10.0f); // BATTERY_PIN_2 (BATCELL2): cell1+cell2 tap, 20k/10k
constexpr float PACK_DIVIDER_RATIO = 10.0f / (33.0f + 10.0f); // BATTERY_PIN_3 (BATCELL3): full pack tap, 33k/10k
uint8_t I2C_ADDRESS = 0x0B;

// Sensor values refreshed every 100ms in loop(); requestEvent()/sendAnswer() (I2C ISR)
// only reads these, it never calls analogRead() itself so it can't stall the I2C bus.
volatile int currentCell1Mv = 0;
volatile int currentCell2Mv = 0;
volatile int currentCell3Mv = 0;
volatile int currentPackMv = 0;
volatile int currentTemperature = 0;
volatile int currentDrawMa = 0; // from INA199
volatile int currentPercent = 0;

void receiveEvent(int bytes);
void requestEvent();
void sendAnswer(byte command);
void cycleCountResponse(int cycleCount);
void designVoltageResponse(int voltage);
void packVoltageResponse(int voltage);
void currentResponse(int current);
void fullChargeCapacityResponse(int capacity);
void remainingCapacityResponse(int capacity);
void temperatureResponse(int temperature);
void relativeStateOfChargeResponse(int stateOfCharge);
void cellVoltage1Response(int voltage);
void cellVoltage2Response(int voltage);
void cellVoltage3Response(int voltage);
int readVoltage(int pin, float dividerRatio);
int getThermistorReading();
int voltageToPercentage(float voltage);
#define CycleCount 0x63
#define DesignVoltage 0x88
#define PackVoltage 0xB8
#define Current 0xCE
#define FullChargeCapacity 0xDA
#define RemainingCapacity 0x50
#define Temperature 0xB0
#define RelativeStateOfCharge 0x59
#define CellVoltage1 0x3C
#define CellVoltage2 0x3F
#define CellVoltage3 0x3C

int cycleCount = 1;
int designCapacity = 1480;
int designVoltage = 11400;
int packVoltage = 12472;
int cur = 64910;
int remainingCapacity = 1104;
int fullChargeCapacity = 1480;
int temp = 2936;
int relativeStateOfCharge = 89;

uint8_t Unknown0xD5Response[] = {0x00, 0x00, 0x4E};
uint8_t DesignCapacityResponse[] = {0xC8, 0x05, 0x44};
uint8_t CycleCountResponse[] = {0x63, 0x00, 0x02}; // for crc 0x16 0x17 0x17 0x63 0x00 = 0x2
uint8_t DesignVoltageResponse[] = {0x88, 0x2C, 0xD6};
uint8_t ManufactureDateResponse[] = {0x3E, 0x4B, 0xF9};
uint8_t SerialNumberResponse[] = {0x98, 0x03, 0x02};
uint8_t ManufacturerNameResponse[] = {0x07, 0x41, 0x54, 0x4C, 0x20, 0x4E, 0x56, 0x54, 0x37, 0x37, 0x37, 0x37, 0x37, 0x37, 0x37, 0x37, 0x37, 0x37, 0x37, 0x37, 0x37, 0x37};
uint8_t DeviceNameResponse[] = {0x06, 0x44, 0x4A, 0x49, 0x30, 0x31, 0x36, 0x66, 0x66, 0x66, 0x66, 0x66, 0x66, 0x66, 0x66, 0x66, 0x66, 0x66, 0x66, 0x66, 0x66, 0x66};
uint8_t PackVoltageResponse[] = {0xB8, 0x30, 0x1C};
uint8_t RelativeStateOfChargeResponse[] = {0x59, 0x00, 0x82};
uint8_t Unknown0x51Response[] = {0x04, 0x00, 0x00, 0x00, 0x00, 0xDA};
uint8_t Unknown0xD2Response[] = {0x00, 0x00, 0x2C};
uint8_t CellVoltage1Response[] = {0x3C, 0x10, 0xC3};
uint8_t CellVoltage2Response[] = {0x3F, 0x10, 0xEA};
uint8_t CellVoltage3Response[] = {0x3C, 0x10, 0xEF};
uint8_t Unknown0xD6Response[] = {0x55, 0xAA, 0x66};
uint8_t Unknown0xD9Response[] = {0x04, 0xE2, 0x17, 0x83, 0xD6, 0xE3};
uint8_t Unknown0xD8Response[] = {0x0E, 0x30, 0x43, 0x30, 0x41, 0x45, 0x39, 0x56, 0x42, 0x33, 0x33, 0x30, 0x31, 0x53, 0x51, 0x60};
uint8_t Unknown0xC2Response[] = {0x08, 0x01, 0x00, 0x00, 0x00, 0x55, 0x00, 0x00, 0x01, 0xAE};
uint8_t ManufacturerData51[] = {0x04, 0x00, 0x00, 0x00, 0x00, 0x54};
uint8_t ManufacturerData53[] = {0x04, 0x00, 0x00, 0x00, 0x00, 0x54};
uint8_t ManufacturerData54[] = {0x04, 0x86, 0x03, 0x06, 0x00, 0xD2};
uint8_t ManufacturerData55[] = {0x02, 0x10, 0x08, 0x16, 0x16, 0x16};

uint8_t Unkown0x2FResponse[] = {0x14, 0x93, 0x8D, 0X0C, 0X00, 0X86, 0X8, 0X90, 0XE6, 0XCD, 0XC8, 0XF8, 0XE2, 0X98, 0XA0, 0X8B, 0XF2, 0X57, 0X4B, 0X10, 0XEE, 0X55};
uint8_t Unkown0x66Response[] = {0x20, 0x94, 0x48, 0xFA, 0x63, 0x01, 0x60, 0xE4, 0x04, 0xA8, 0x10, 0xB1, 0x10, 0x0, 0x0, 0x0, 0x0, 0xEC, 0x04, 0x0, 0x0, 0x0A, 0x32, 0x1A, 0x17, 0x0, 0x0, 0x0, 0x0, 0x0, 0x0, 0xC8};
uint8_t Unkown0x23Response[] = {0x4, 0x00, 0x00, 0x00, 0x00, 0x54};

uint8_t lastCommandIn = 0;
uint8_t lastManufacturerDataAddressIn = 0;

#define SMBUS_CRC8_POLY 0x07
uint8_t pec(uint8_t *data, uint8_t len)
{
  uint8_t crc = 0;
  for (int i = 0; i < len; i++)
  {
    crc ^= data[i];
    for (int j = 0; j < 8; j++)
    {
      if (crc & 0x80)
      {
        crc = (crc << 1) ^ SMBUS_CRC8_POLY;
      }
      else
      {
        crc <<= 1;
      }
    }
  }
  return crc;
}
void setup()
{
  // pinMode(MOTOR_PIN, OUTPUT);
  Wire.begin(I2C_ADDRESS);

  Wire.onRequest(requestEvent);
  Wire.onReceive(receiveEvent);
  pinMode(LED_PIN, OUTPUT);
  Serial.begin(115200);
  Serial.println("I2C Slave started");
}

void loop()
{
  static unsigned long lastSensorUpdateMs = 0;

  if (millis() - lastSensorUpdateMs < 100)
  {
    return;
  }
  lastSensorUpdateMs = millis();

  int cell1Mv = readVoltage(BATTERY_PIN_1, CELL1_DIVIDER_RATIO);     // BATCELL1 tap: cell1 only
  int upToCell2Mv = readVoltage(BATTERY_PIN_2, CELL2_DIVIDER_RATIO); // BATCELL2 tap: cell1+cell2
  int packMv = readVoltage(BATTERY_PIN_3, PACK_DIVIDER_RATIO);       // BATCELL3 tap: full pack (cell1+cell2+cell3)

  currentCell1Mv = max(cell1Mv, 1000);
  currentCell2Mv = max(upToCell2Mv - cell1Mv, 1000);
  currentCell3Mv = max(packMv - upToCell2Mv, 1000);
  currentPackMv = max(packMv, 3000);

  currentPercent = voltageToPercentage(currentPackMv / 1000.0f);
  currentTemperature = getThermistorReading();

  // INA199: Vout(mV) = I(A) * Rshunt(0.002R) * Gain(50) = I(A) * 100mV/A -> I(mA) = Vout(mV) * 10
  int currentAdc = analogRead(CURRENT_PIN);
  float currentMv = currentAdc * (ADCReferanceVoltage * 1000.0f / 1024.0f);
  currentDrawMa = (int)(currentMv * 10.0f);
}

void receiveEvent(int bytes)
{
  digitalWrite(LED_PIN, HIGH);
  lastCommandIn = Wire.read();
  // Serial.print("  : 0x");
  // Serial.println(lastCommandIn, HEX);
  switch (lastCommandIn)
  {
  case ManufacturerDataRequest:
    lastManufacturerDataAddressIn = Wire.read();
    Wire.read();
    Wire.read();
    break;
  case 0xD3:
    Wire.read();
    Wire.read();
    Wire.read();
    break;
  default:
    break;
  }
  digitalWrite(LED_PIN, LOW);
}

void requestEvent()
{
  sendAnswer(lastCommandIn);
}
void sendAnswer(byte command)
{
  // Serial.print("snd: 0x");
  // Serial.println(command, HEX);
  switch (command)
  {
  case Unknown0xD5Request:
    Wire.write(Unknown0xD5Response, sizeof(Unknown0xD5Response));
    break;
  case DesignCapacityRequest:
    Wire.write(DesignCapacityResponse, sizeof(DesignCapacityResponse));
    break;
  case CycleCountRequest:
    cycleCountResponse(cycleCount);
    break;
  case DesignVoltageRequest:
    Wire.write(DesignVoltageResponse, sizeof(DesignVoltageResponse));
    break;
  case ManufactureDateRequest:
    Wire.write(ManufactureDateResponse, sizeof(ManufactureDateResponse));
    break;
  case SerialNumberRequest:
    Wire.write(SerialNumberResponse, sizeof(SerialNumberResponse));
    break;
  case ManufacturerNameRequest:
    Wire.write(ManufacturerNameResponse, sizeof(ManufacturerNameResponse));
    break;
  case DeviceNameRequest:
    Wire.write(DeviceNameResponse, sizeof(DeviceNameResponse));
    break;
  case ManufacturerDataRequest:
    switch (lastManufacturerDataAddressIn)
    {
    case 0x51:
      Wire.write(ManufacturerData51, sizeof(ManufacturerData51));
      break;
    case 0x53:
      Wire.write(ManufacturerData53, sizeof(ManufacturerData53));
      break;
    case 0x54:
      Wire.write(ManufacturerData54, sizeof(ManufacturerData54));
      break;
    case 0x55:
      Wire.write(ManufacturerData55, sizeof(ManufacturerData55));
      break;
    }
    // Wire.write(ManufacturerDataResponse, sizeof(ManufacturerDataResponse));
    break;
  case PackVoltageRequest:
    packVoltageResponse(currentPackMv);
    break;
  case CurrentRequest:
    currentResponse(currentDrawMa);
    break;
  case FullChargeCapacityRequest:
    fullChargeCapacityResponse(fullChargeCapacity); // kept equal to designCapacity (1480mAh)
    break;
  case RemainingCapacityRequest:
    remainingCapacityResponse((designCapacity * currentPercent) / 100);
    break;
  case TemperatureRequest:
    temperatureResponse(currentTemperature);
    break;
  case RelativeStateOfChargeRequest:
    relativeStateOfChargeResponse(currentPercent);
    break;
  case Unknown0x51Request:
    Wire.write(Unknown0x51Response, sizeof(Unknown0x51Response));
    break;
  case Unknown0xD2Request:
    Wire.write(Unknown0xD2Response, sizeof(Unknown0xD2Response));
    break;
  case CellVoltage1Request:
    cellVoltage1Response(currentCell1Mv);
    break;
  case CellVoltage2Request:
    cellVoltage2Response(currentCell2Mv);
    break;
  case CellVoltage3Request:
    cellVoltage3Response(currentCell3Mv);
    break;
  case Unknown0xD6Request:
    Wire.write(Unknown0xD6Response, sizeof(Unknown0xD6Response));
    break;
  case Unknown0xD9Request:
    Wire.write(Unknown0xD9Response, sizeof(Unknown0xD9Response));
    break;
  case Unknown0xD8Request:
    Wire.write(Unknown0xD8Response, sizeof(Unknown0xD8Response));
    break;
  case Unknown0xC2Request:
    Wire.write(Unknown0xC2Response, sizeof(Unknown0xC2Response));
    break;
  case Unknown0x2FRequest:
    Wire.write(Unkown0x2FResponse, sizeof(Unkown0x2FResponse));
    break;
  case Unkown0x66Request:
    Wire.write(Unkown0x66Response, sizeof(Unkown0x66Response));
    break;
  case ManufacturerReadRequest:
    Wire.write(Unkown0x23Response, sizeof(Unkown0x23Response));
    break;

  default:
    // Unknown command: no response sent. Do not Serial.print here, this runs in the I2C ISR.
    break;
  }
}
// void cycleCountResponse()
// {
//   uint8_t rawdata[4];

//   rawdata[0] = 0x0B;
//   rawdata[1] = cycleCount & 0xFF;
//   rawdata[2] = (cycleCount >> 8) & 0xFF;

//   uint8_t temp[5] = {0x16, 0x17, 0x17, rawdata[1], rawdata[2]};
//   rawdata[3] = pec(temp, 5);
//   Wire.write(rawdata, 4);

// }
void cycleCountResponse(int cyclecount)
{
  uint8_t rawdata[4];

  rawdata[0] = cyclecount & 0xFF;
  rawdata[1] = (cyclecount >> 8) & 0xFF;

  uint8_t temp[5] = {0x16, CycleCountRequest, 0x17, rawdata[0], rawdata[1]};
  rawdata[2] = pec(temp, 5);

  Wire.write(rawdata, 3);
  // Serial.print("cycle count raw data: ");
  // for (int i = 0; i < 4; i++)
  // {
  //   Serial.print(rawdata[i], HEX);
  //   Serial.print(" ");
  // }
  // Serial.println();
}
void designVoltageResponse(int voltage)
{
  uint8_t rawdata[3];

  rawdata[0] = voltage & 0xFF;
  rawdata[1] = (voltage >> 8) & 0xFF;
  rawdata[2] = 0x00; // this is pec value that will change after calculating the pec

  uint8_t temp[5] = {0x16, DesignVoltageRequest, 0x17, rawdata[0], rawdata[1]};
  uint8_t calculatedPEC = pec(temp, 5);

  rawdata[2] = calculatedPEC;

  Wire.write(rawdata, 3);

  // Serial.print("Raw data: ");
  // for (int i = 0; i < 3; i++)
  // {
  //   Serial.print(rawdata[i], HEX);
  //   Serial.print(" ");
  // }
  // Serial.println();
}

void packVoltageResponse(int voltage)
{
  uint8_t rawdata[3];

  rawdata[0] = voltage & 0xFF;
  rawdata[1] = (voltage >> 8) & 0xFF;
  rawdata[2] = 0x00; // this is pec value that will change after calculating the pec

  uint8_t temp[5] = {0x16, PackVoltageRequest, 0x17, rawdata[0], rawdata[1]};
  uint8_t calculatedPEC = pec(temp, 5);

  rawdata[2] = calculatedPEC;

  Wire.write(rawdata, 3);

  // Serial.print("Raw data: ");
  // for (int i = 0; i < 3; i++)
  // {
  //   Serial.print(rawdata[i], HEX);
  //   Serial.print(" ");
  // }
  // Serial.println();
}

void currentResponse(int current)
{
  uint8_t rawdata[3];

  rawdata[0] = current & 0xFF;
  rawdata[1] = (current >> 8) & 0xFF;
  rawdata[2] = 0x00; // this is pec value that will change after calculating the pec

  uint8_t temp[5] = {0x16, CurrentRequest, 0x17, rawdata[0], rawdata[1]};
  uint8_t calculatedPEC = pec(temp, 5);

  rawdata[2] = calculatedPEC;

  Wire.write(rawdata, 3);
}

void fullChargeCapacityResponse(int capacity)
{
  uint8_t rawdata[3];

  rawdata[0] = capacity & 0xFF;
  rawdata[1] = (capacity >> 8) & 0xFF;
  rawdata[2] = 0x00; // this is pec value that will change after calculating the pec

  uint8_t temp[5] = {0x16, FullChargeCapacityRequest, 0x17, rawdata[0], rawdata[1]};
  uint8_t calculatedPEC = pec(temp, 5);

  rawdata[2] = calculatedPEC;

  Wire.write(rawdata, 3);
}
void remainingCapacityResponse(int remainingcapacity)
{
  uint8_t rawdata[3];

  rawdata[0] = remainingcapacity & 0xFF;
  rawdata[1] = (remainingcapacity >> 8) & 0xFF;
  rawdata[2] = 0x00; // this is pec value that will change after calculating the pec

  uint8_t temp[5] = {0x16, RemainingCapacityRequest, 0x17, rawdata[0], rawdata[1]};
  uint8_t calculatedPEC = pec(temp, 5);

  rawdata[2] = calculatedPEC;

  Wire.write(rawdata, 3);
}
void relativeStateOfChargeResponse(int stateofcharge)
{
  uint8_t rawdata[3];

  rawdata[0] = stateofcharge & 0xFF;
  rawdata[1] = (stateofcharge >> 8) & 0xFF;
  rawdata[2] = 0x00; // this is pec value that will change after calculating the pec

  uint8_t temp[5] = {0x16, RelativeStateOfChargeRequest, 0x17, rawdata[0], rawdata[1]};
  uint8_t calculatedPEC = pec(temp, 5);

  rawdata[2] = calculatedPEC;

  Wire.write(rawdata, 3);
}
void temperatureResponse(int temperature)
{
  uint8_t rawdata[3];

  rawdata[0] = temperature & 0xFF;
  rawdata[1] = (temperature >> 8) & 0xFF;
  rawdata[2] = 0x00; // this is pec value that will change after calculating the pec

  uint8_t temp[5] = {0x16, TemperatureRequest, 0x17, rawdata[0], rawdata[1]};
  uint8_t calculatedPEC = pec(temp, 5);

  rawdata[2] = calculatedPEC;

  Wire.write(rawdata, 3);
}
void cellVoltage1Response(int voltage)
{
  uint8_t rawdata[3] = {0x3C, 0x10, 0x00};

  rawdata[0] = voltage & 0xFF;
  rawdata[1] = (voltage >> 8) & 0xFF;
  rawdata[2] = 0x00; // this is pec value that will change after calculating the pec

  uint8_t temp[5] = {0x16, CellVoltage1Request, 0x17, rawdata[0], rawdata[1]};

  rawdata[2] = pec(temp, 5);

  Wire.write(rawdata, 3);

  // Serial.print("Raw data: ");
  // for (int i = 0; i < 3; i++)
  // {
  //   Serial.print(rawdata[i], HEX);
  //   Serial.print(" ");
  // }
  // Serial.println();
}

void cellVoltage2Response(int voltage)
{
  uint8_t rawdata[3];

  rawdata[0] = voltage & 0xFF;
  rawdata[1] = (voltage >> 8) & 0xFF;
  rawdata[2] = 0x00; // this is pec value that will change after calculating the pec

  uint8_t temp[5] = {0x16, CellVoltage2Request, 0x17, rawdata[0], rawdata[1]};

  rawdata[2] = pec(temp, 5);

  Wire.write(rawdata, 3);

  // Serial.print("Raw data: ");
  // for (int i = 0; i < 3; i++)
  // {
  //   Serial.print(rawdata[i], HEX);
  //   Serial.print(" ");
  // }
  // Serial.println();
}

void cellVoltage3Response(int voltage)
{
  uint8_t rawdata[3];

  rawdata[0] = voltage & 0xFF;
  rawdata[1] = (voltage >> 8) & 0xFF;
  rawdata[2] = 0x00; // this is pec value that will change after calculating the pec

  uint8_t temp[5] = {0x16, CellVoltage3Request, 0x17, rawdata[0], rawdata[1]};

  rawdata[2] = pec(temp, 5);

  Wire.write(rawdata, 3);

  // Serial.print("Raw data: ");
  // for (int i = 0; i < 3; i++)
  // {
  //   Serial.print(rawdata[i], HEX);
  //   Serial.print(" ");
  // }
  // Serial.println();
}
// int readVoltage(int pin) {
//   int sensorValue = analogRead(pin);
//   float voltage = sensorValue * (3.3 / 1023.0);
//   return (int)(voltage*1000);
// }
int readVoltage(int pin, float dividerRatio)
{
  int result = (int)((analogRead(pin) * ADCReferanceVoltage) / 1024.0 / dividerRatio * 1000.0f);
  return result;
}
int getThermistorReading()
{
  // No NTC wired up. SMBus TemperatureRequest expects 0.1K units:
  // (25.0 + 273.15) * 10 = 2982, i.e. a fixed 25C reading.
  return 2982;
}
int voltageToPercentage(float voltage)
{
  // 3S LiPo pack: 4.2V/cell peak
  const float maxVoltage = 12.6;
  const float minVoltage = 9.0;

  // Clamp the input voltage between min and max values
  voltage = constrain(voltage, minVoltage, maxVoltage);

  // Calculate the percentage
  float percentage = (voltage - minVoltage) / (maxVoltage - minVoltage) * 100;

  return (int)percentage;
}
